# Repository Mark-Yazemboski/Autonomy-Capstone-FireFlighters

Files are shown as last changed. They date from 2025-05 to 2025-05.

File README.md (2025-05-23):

# 🔥 Autonomous Fire Fighting Drone

## A functional, affordable, and easily buildable drone capable of searching an area, detecting a heat source, and deploying a payload.  
🏆 **First Place Winner – Senior Capstone Showcase**

This senior capstone project’s objective was to design and build a drone capable of autonomously searching a designated area, locating a simulated fire using a thermal camera, and deploying a fire suppressant. Teams were given only the following components: an **Arduino**, a **thermal camera**, a **transmitter/receiver**, and an **IMU**.

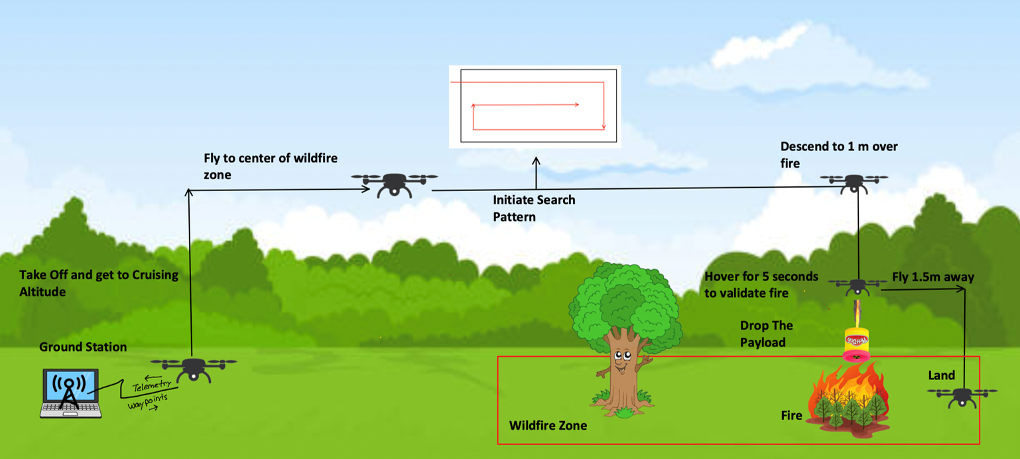
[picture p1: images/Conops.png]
Mission Concept


> 👨‍🚒 **Team Name:** *The FireFlighters*

---

## 📸 Team Photo

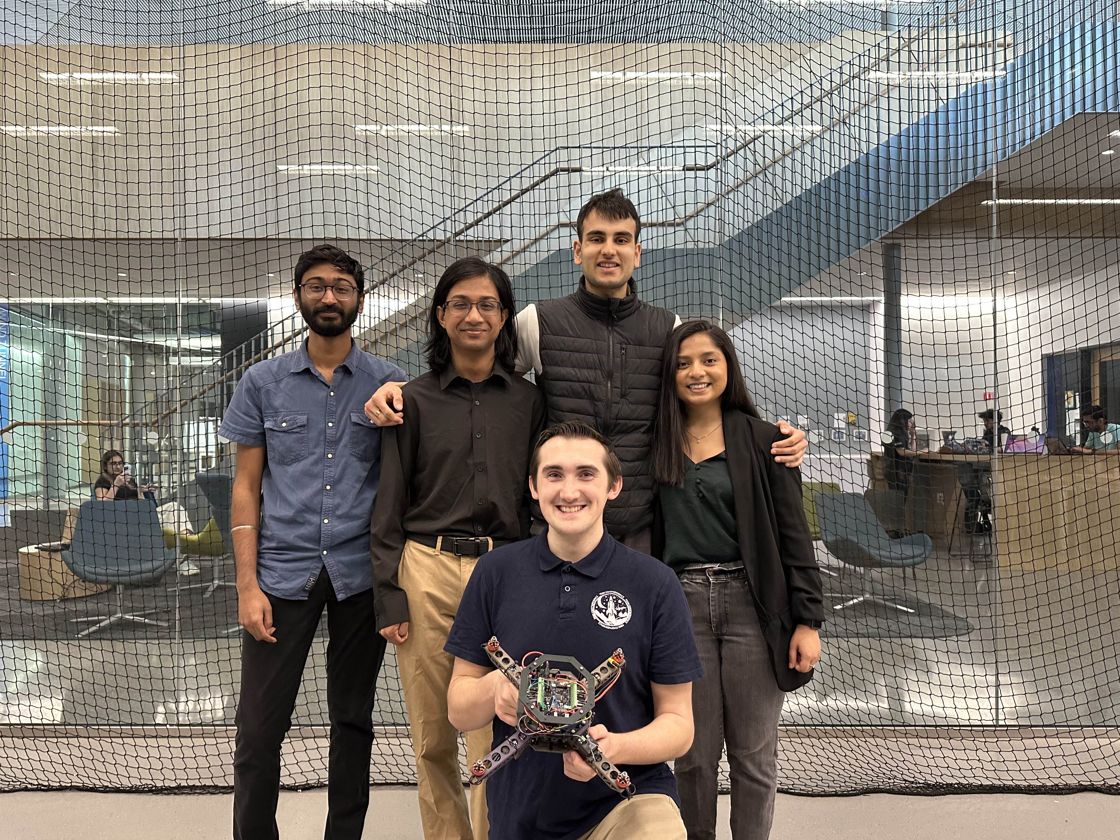
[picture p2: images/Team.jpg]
Team Photo


**Team Members (left to right):**

- **Achutan Srinivasan** – Back Left  
- **Ankur Ghorai** – Back Middle Left  
- **Jaisel Singh** – Back Middle Right  
- **Trusha Patel** – Back Right  
- **Mark Yazemboski** (👋 Me, Front) – *Team Lead*

---

## 🛠️ Key Design Principles

We focused on four core physical design goals:

- ✅ Fully 3D-printed frame  
- 🛒 Easily obtainable parts (Amazon, GetFPV, etc.)  
- 🧩 Modular, repairable design  
- ⚡ Clean and efficient wire management  

---

## 💡 Design Rationale

After studying past teams, we identified key ways to improve:

- **3D-printed frame** for rapid repair and low cost  
- **Fast-shipping parts** to avoid long lead times  
- **Modular design** allowed broken parts (like arms) to be replaced in hours  
- **Wire routing** designed into the frame to prevent tangles and shorts  

---

## 🧠 Drone Architecture (CAD Model)

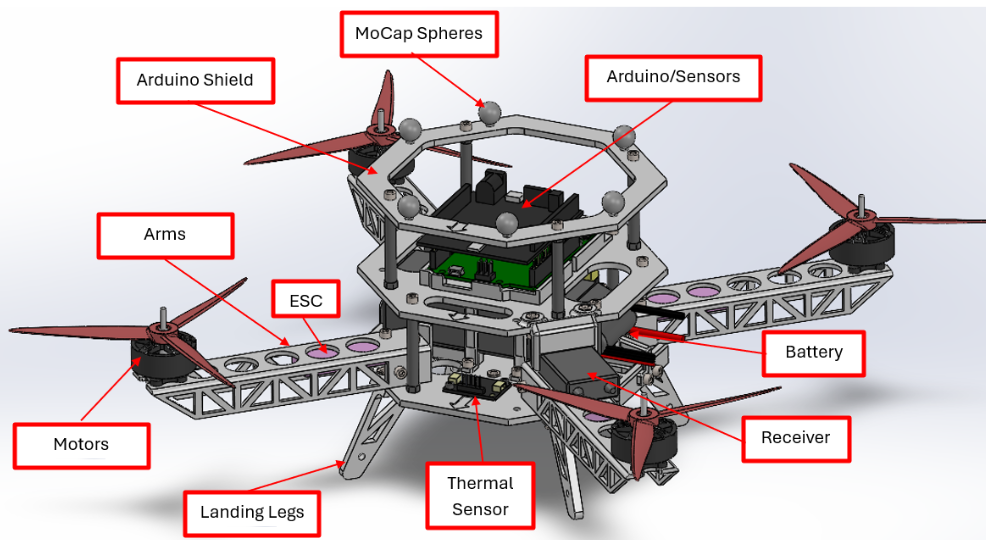
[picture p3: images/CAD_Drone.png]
CAD Model


A three-tier frame layout:

1. **Base Plate**  
   - Mounts arms, battery, PDB, payload, and ESCs  
   - Central structure for mechanical and electrical subsystems  

2. **Top Plate**  
   - Mounts the Arduino and IMU  
   - Raised to reduce EMI from high-current motor lines  

3. **Shield**  
   - Holds MoCap markers for position tracking  
   - Protects sensitive electronics during crashes  

---

## ✈️ Arm Design

The custom arm design used a **C-beam profile with trusses**:

- **C-channel** let us route ESCs and wires inside the arm  
- **Trusses** reduced weight while maintaining strength  
- These features improved stiffness and flight stability despite the printed frame  

---

## 🖨️ 3D Printing & Cost Efficiency

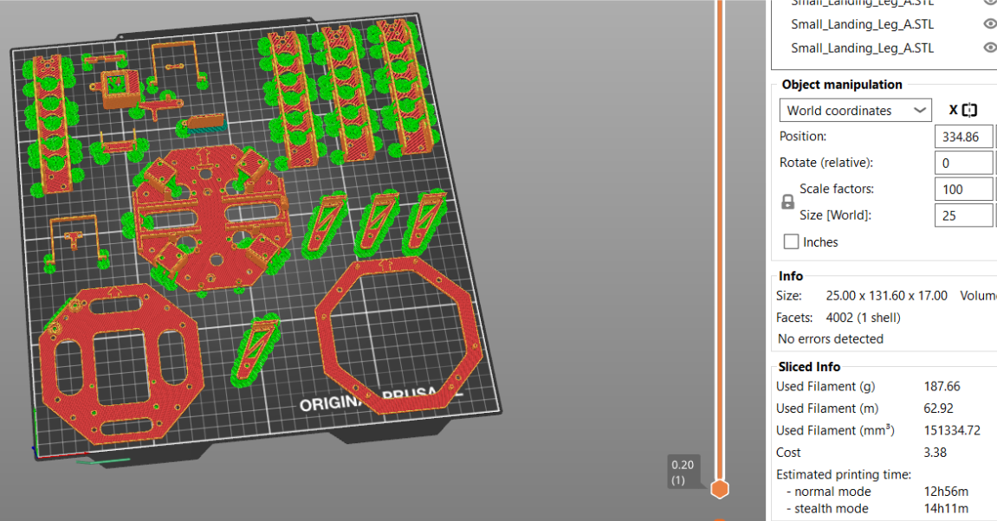
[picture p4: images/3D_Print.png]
3D Print Layout


- Printed using **PLA on a Prusa XL**  
- **Total print time:** ~13 hours  
- **Material cost:** ~$3.38  
- Demonstrated that UAVs can be affordable and manufacturable quickly  

---

## 📂 Repository Contents

- **Drone CAD/** – All SolidWorks models with accurate weight/inertia  
- **STL_and_Prusa_Files/** – Printable files for all drone parts + pre-arranged Prusa slicer project  
- **Build_Book.pdf** – Step-by-step construction and setup guide  
- **FireFlighters_Drone_BOM.xlsx** – Full bill of materials with costs and part links  
- **ManualFlightCode/** – Arduino code for manual RC flight  
- **HandCarryCode/** – Contains full autonomy logic (not flight-ready)  
- **Matlab_Kalman_Filter_Prototype.m** – MATLAB simulation of the onboard Kalman Filter  
- **Thermal_Sensor_Simulation.py** – Python simulation of the thermal camera behavior  
- **Final_Report.pdf** – Technical report covering the full design, testing, and conclusions  

---

## 🧪 Issues Encountered

The **Arduino Uno**, while functional, lacks the processing power and **multithreading capabilities** needed for real-time autonomous flight. Specifically:

- The **GCS communication protocol** took ~100 ms per loop iteration  
- This limited the control loop to ~2 Hz (instead of the desired 100+ Hz)  
- The drone couldn't stabilize itself while processing communication, sensor input, and control logic all on the same thread  

As a workaround, the drone was hand-carried during the demo to showcase data transmission, Kalman filter-based orientation and position estimation, waypoint tracking, search pattern execution, thermal detection, and payload deployment.

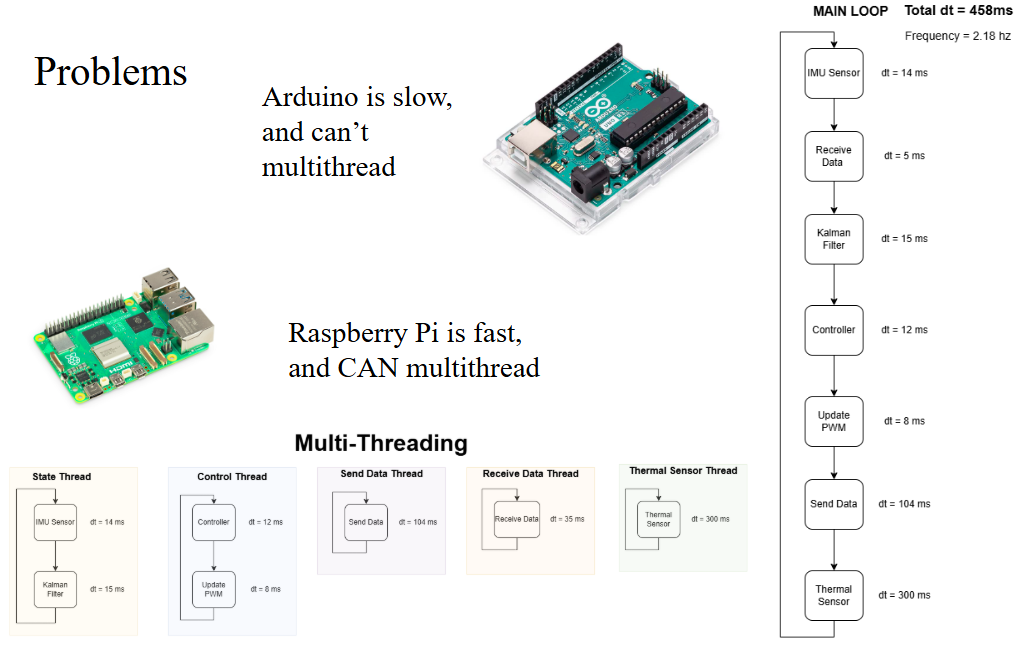
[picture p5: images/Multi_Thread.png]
Multithreading Bottleneck


### 🔧 Future Recommendation

Next year's team will upgrade to a **Raspberry Pi**, which supports:

- Multithreading (e.g., separate threads for GCS comms and control loop)  
- Faster processing for real-time autonomy  
- More flexible development in Python or C++  

---

## 🧾 Conclusion

This capstone project was an incredible learning experience. Building a product from the ground up taught me far more than I expected—not just about **CAD** and designing components for manufacturability and ease of assembly, but also about algorithms and core topics in **autonomy**.

I deepened my understanding of **Kalman filters** (my personal favorite), learned how to implement **cascade PID controllers**, developed **waypoint navigation**, and wrote the full autonomy codebase. This project challenged and refined my programming skills and solidified my passion for **Guidance, Navigation, and Control (GNC)** and **autonomous systems**.

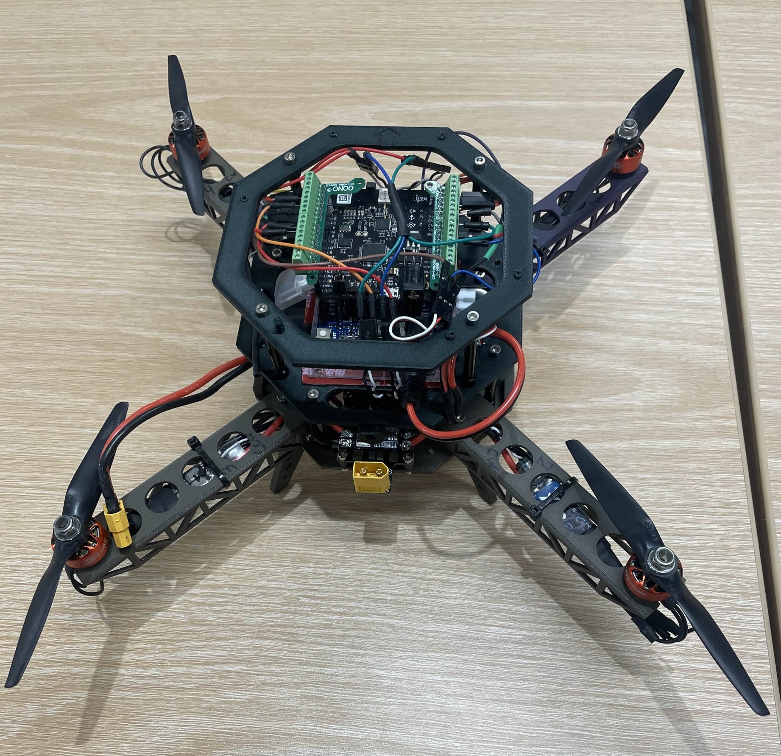
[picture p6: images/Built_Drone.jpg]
Final Drone


Thank you!

## 📄 Final Report

For complete technical details on design, components, control logic, testing, and results, see the [**Final Report**](Final_Report.pdf).

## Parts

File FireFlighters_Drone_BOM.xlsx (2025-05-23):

FireFlighters Drone BOM
Part Description | Model (if available) | Website (just name) | Units | Cost per Unit | Total | Comments | Links
Prop | B5x3E-B4 | APC Props | 1 | $5.63 | $5.63 |  | Link (https://www.apcprop.com/product/b5x3e-b4/)
Motor | RCINPOWER SmooX 1507 | Get FPV | 4 | $18.99 | $75.96 | Orange Color, 2680KV | Link (https://www.getfpv.com/rcinpower-smoox-1507-plus-2680kv-3800kv-4200kv-motor.html)
ESC | XILO 40A BLHeli_S 2-4s ESC | Get FPV | 4 | $12.99 | $51.96 |  | Link (https://www.getfpv.com/xilo-40a-blheli-s-2-4s-esc.html)
Battery | OVONIC 4s Lipo 2200 mAh | Amazon | 1 | $25.99 | $25.99 |  | Link (https://www.amazon.com/2200mAh-Airplane-Quadcopter-Helicopter-Multi-Motor/dp/B07MLF5G1T)
Spacers | Aluminum Standoff Spacer | Amazon | 2 | $11.99 | $23.98 |  | Link (https://www.amazon.com/dp/B0B97H2WJ7?ref=ppx_yo2ov_dt_b_fed_asin_title)
M2 screw | M2 Screws Kit M2 Bolts Kit | Amazon | 1 | $8.99 | $8.99 |  | Link (https://www.amazon.com/dp/B0D3X4LJD2?ref=ppx_yo2ov_dt_b_fed_asin_title)
M3 Screw | M3 Small Metric Screws | Amazon | 1 | $15.99 | $15.99 |  | Link (https://www.amazon.com/dp/B0CMQG542V?ref=ppx_yo2ov_dt_b_fed_asin_title)
PDB | Matek Systems PDB-XT60 W/ BEC 5V & 12V 2oz Copper For RC Multirotors | Foxtech FPV | 1 | $4.49 | $4.49 |  | Link (https://www.foxtechfpv.com/matek-pdb-xt60-for-rc-multirotors.html)
Arduino Terminal Block | Ultra-Small GPIO Terminal Block Breakout Board Module for Arduino UNO R3 | Amazon | 1 | $18.90 | $18.90 |  | Link (https://www.amazon.com/dp/B08XWCN43C?ref=ppx_yo2ov_dt_b_fed_asin_title)
Servo | Turnigy TGY-1551A Analog Micro Servo 24T 1.0kg / 0.08sec / 5g | Hobby King | 1 | $2.39 | $2.39 |  | Link (https://hobbyking.com/en_us/turnigy-tgy-1551a-analog-micro-servo-1-0kg-0-08sec-5g.html)
Arduino | Arduino Uno R4 Wifi | Arduino | 1 | $27.50 | $27.50 |  | Link (https://store-usa.arduino.cc/products/uno-r4-wifi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)
Pozyx | Pozyx Shield V1.6 | Pozyx | 1 | $20.00 | $20.00 | Out of Stock | Link (https://www.pozyx.io/products/hardware/tags/developer-tag)
Reciever/Transmitter | FS-i6X 10CH 2.4GHz RC Transmitter Controller with FS-iA6B Receiver | Amazon | 1 | $58.84 | $58.84 |  | Link (https://www.amazon.com/FLYSKY-Transmitter-Controller-Receiver-Upgrade/dp/B07Z8VCB45)
Arduino Power Cord | 5 Pcs 5.5x2.1mm Male for Power Plug Connector CCTV Pigtail Cable 12V | Amazon | 1 | $5.71 | $5.71 | Comes with 5 | Link (https://www.amazon.com/Hxyxbnhno-5-5x2-1mm-Power-Connector-Pigtail/dp/B0DGSSD4BF)
Zipties | Cable Zip Ties,400 Pack Black Assorted Sizes 12+8+6+4 Inch,Multi-Purpose Self-Locking | Amazon | 1 | $5.99 | $5.99 |  | Link (https://www.amazon.com/HAVE-ME-TD-Cable-Ties/dp/B08TVLYB3Q?s=electronics)
Electrical Tape | 0.62 in x 49 ft, 3 Pack, Electric Tape | Amazon | 1 | $4.85 | $4.85 |  | Link (https://www.amazon.com/Bates-Black-Electrical-8A9Wt3hrxTG8qXQFjeyNLkF9a9AJPfWWxSc6Fyv4suBe2xqZMGFbhrnMSRysAEYuT7LzpBsTYM4RJ8V2xWghttbNRG4Luiu-Eletrical/dp/B0B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)
Type C to USB | able 3ft, 2-Pack USB A to Type C Charger Cord Fast Charging | Amazon | 1 | $5.99 | $5.99 |  | Link (https://www.amazon.com/Charging-etguuds-Charger-Compatible-Samsung/dp/B089DM4KDW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)
PLA | PLA Filament | Amazon | 1 | $14.99 | $14.99 | Any Color | Link (https://www.amazon.com/OVERTURE-Filament-Consumables-Dimensional-Accuracy/dp/B07PGZNM34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)
Wire | 22 awg Wire Solid Core Hookup | Amazon | 1 | $15.19 | $15.19 | 22 AWG 6 Colors Solid Wire Kit | Link (https://www.amazon.com/TUOFENG-Electronic-Prototyping-Circuits-Breadboarding/dp/B07TX6BX47?s=industrial)
Thermal Camera | Adafruit MLX90640 IR Thermal Camera Breakout - 55 Degree | Adafruit | 1 | $74.95 | $74.95 | Optional for manual flight | Link (https://www.adafruit.com/product/4407)
Color Code |  | Total Cost
Nessesary Items |  | $346.33
Items you might already own |  | $47.01
Optional/ Wont effect manual flight |  | $74.95
Full Cost for Everything
$468.29

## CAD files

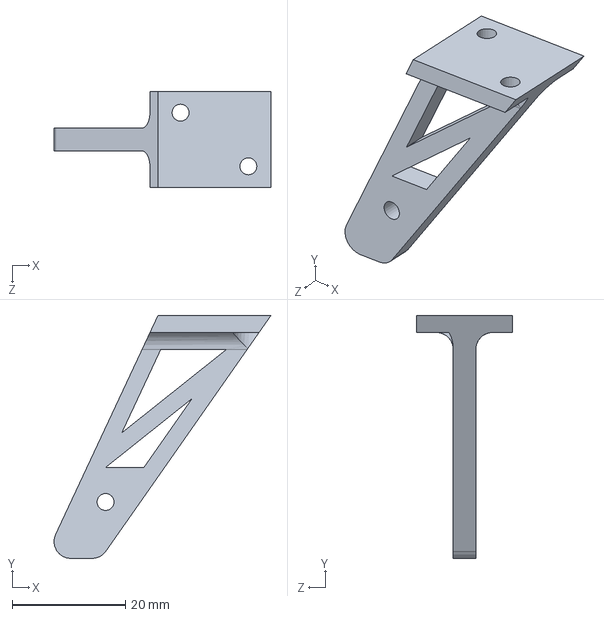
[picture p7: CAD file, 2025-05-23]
Drone CAD/Frame-Structural-Models/Small_Landing_Leg_A.SLDPRT
38.4 x 43.0 x 17.0 mm

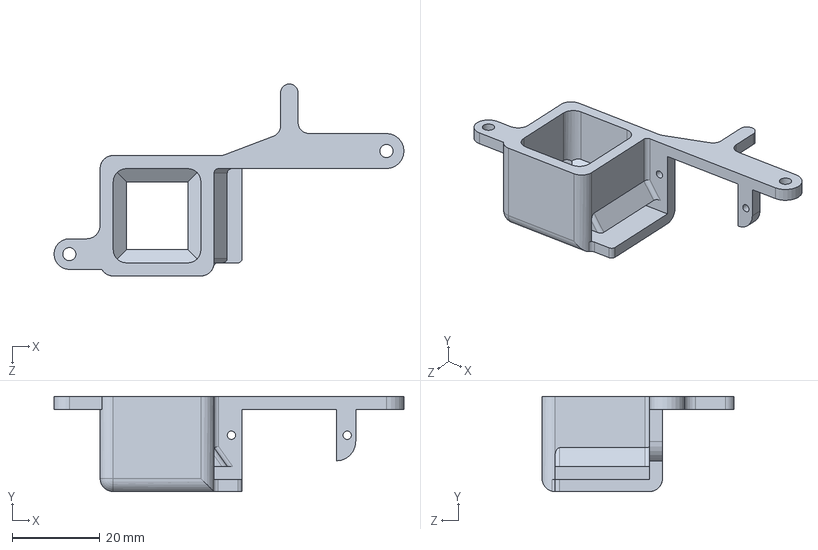
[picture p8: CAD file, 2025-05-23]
Drone CAD/New_Sliding_Door_Payload_Mechanism/Payload_Mount_E.SLDPRT
79.8 x 21.7 x 43.8 mm

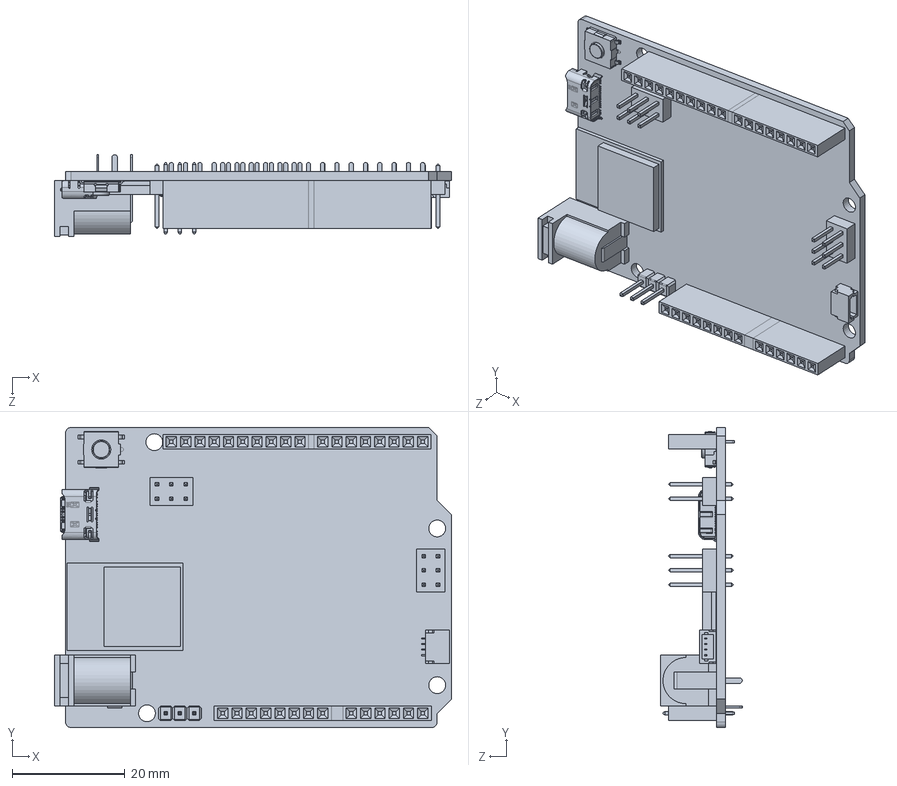
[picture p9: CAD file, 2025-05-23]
Drone CAD/Sensors-Electronics/Arduino_Uno_R4_Wifi_A.SLDPRT
70.5 x 53.3 x 14.5 mm

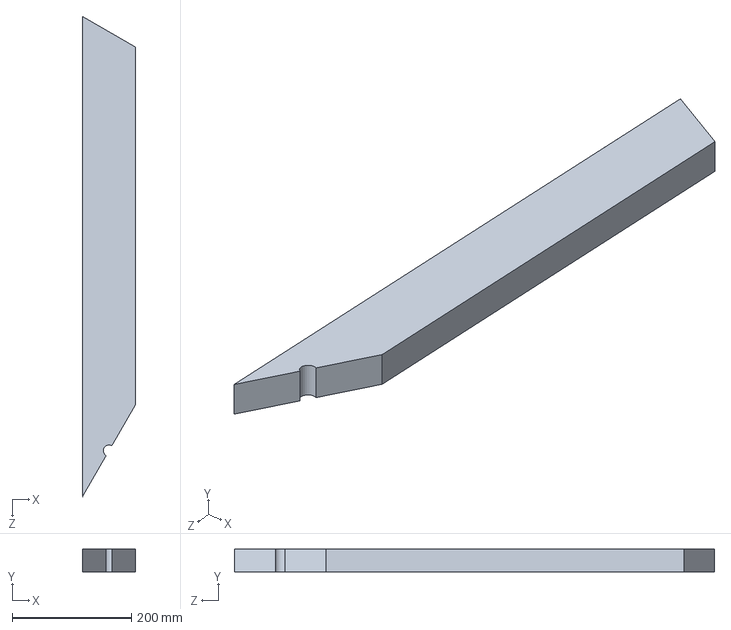
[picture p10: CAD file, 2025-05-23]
Drone CAD/Test_Stand/Long_2by4.SLDPRT
88.9 x 38.1 x 806.6 mm

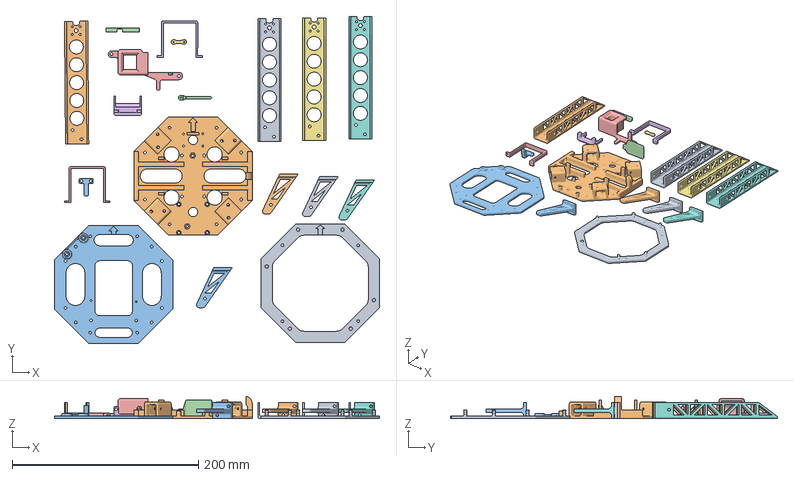
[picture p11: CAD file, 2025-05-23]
STL_and_Prusa_Files/Entire_Drone_Prusa_XL.3mf
348.6 x 351.2 x 23.8 mm
6inch_Arm_D.STL x 4
Battery_Holder_D.STL
Flat_Head_Pin_E.STL
Payload_Mount_E.STL
Reciever_Holder_B.STL
Servo_To_Flat_Head_Pin_C.STL
Small_Landing_Leg_A.STL x 4
Shield_Plate_C.STL
Base_Plate_G.STL
Top_Plate_E.STL
PDB_Wire_Holder_A.STL
Battery_Bracket_B.STL x 2

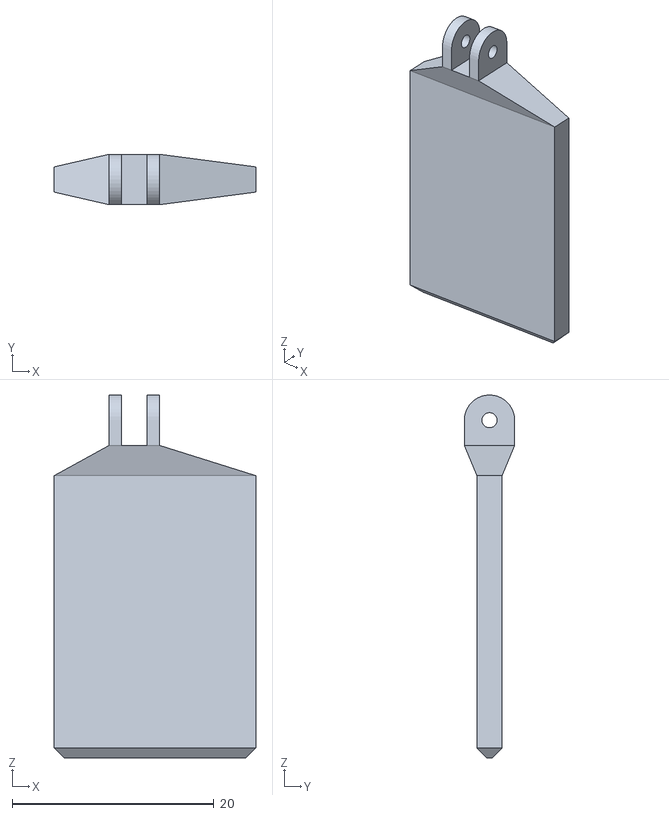
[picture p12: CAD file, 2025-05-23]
STL_and_Prusa_Files/STLs/Flat_Head_Pin_E.STL
20.0 x 5.00 x 36.0

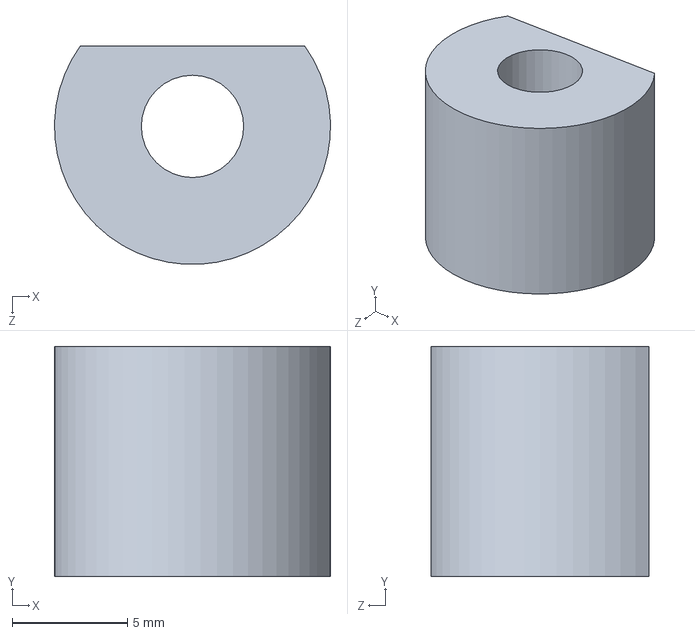
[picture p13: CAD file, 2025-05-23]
Drone CAD/Frame-Structural-Models/Wire_Cylinder.SLDPRT
12.0 x 10.0 x 9.49 mm

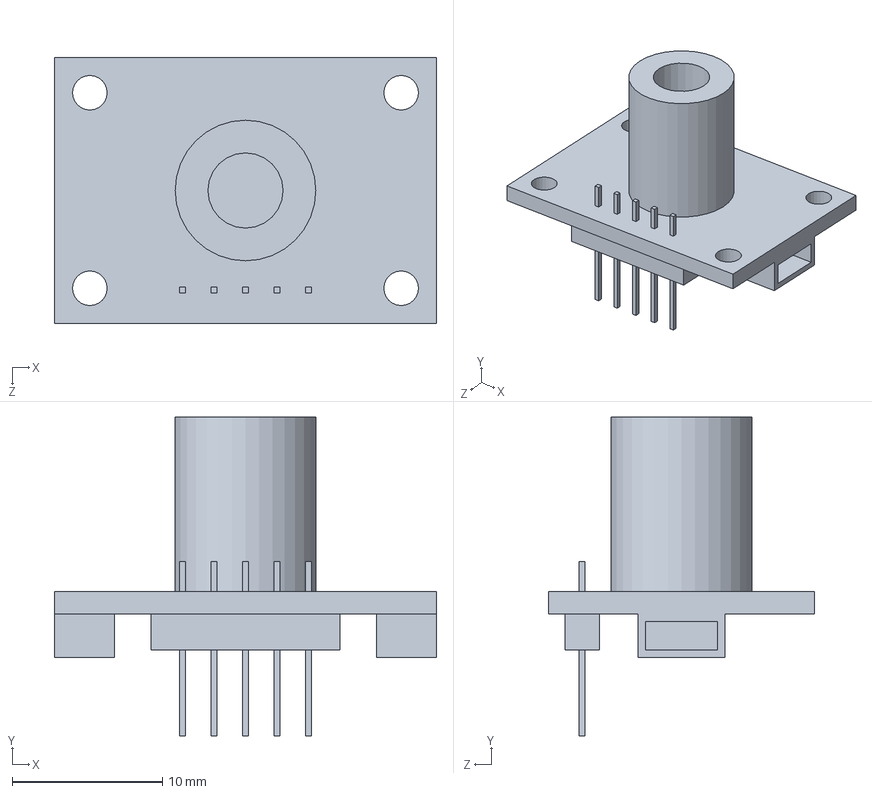
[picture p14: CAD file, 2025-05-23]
Drone CAD/Sensors-Electronics/IR_Sensor_B.SLDPRT
25.4 x 21.2 x 17.7 mm

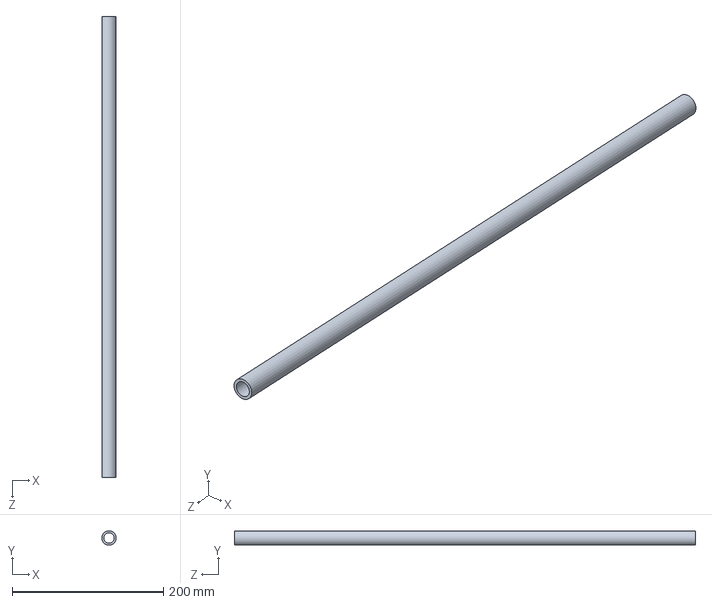
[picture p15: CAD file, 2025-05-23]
Drone CAD/Test_Stand/Rod.SLDPRT
19.1 x 19.0 x 609.6 mm

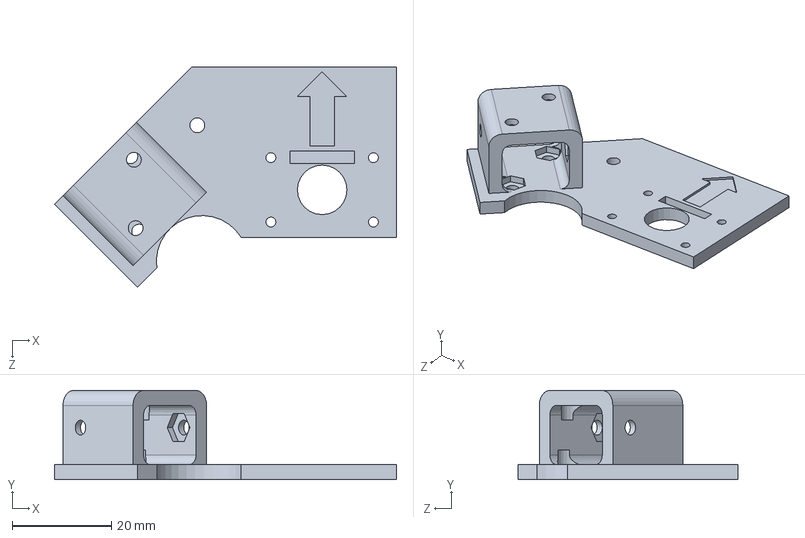
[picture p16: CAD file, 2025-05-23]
Drone CAD/Tests/Thermal_Arm_Test.SLDPRT
69.0 x 18.0 x 44.5 mm

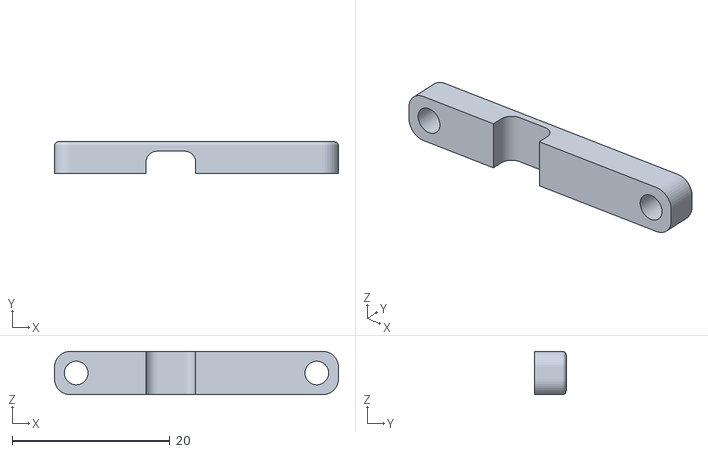
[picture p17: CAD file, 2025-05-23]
STL_and_Prusa_Files/STLs/PDB_Wire_Holder_A.STL
36.0 x 4.00 x 5.50

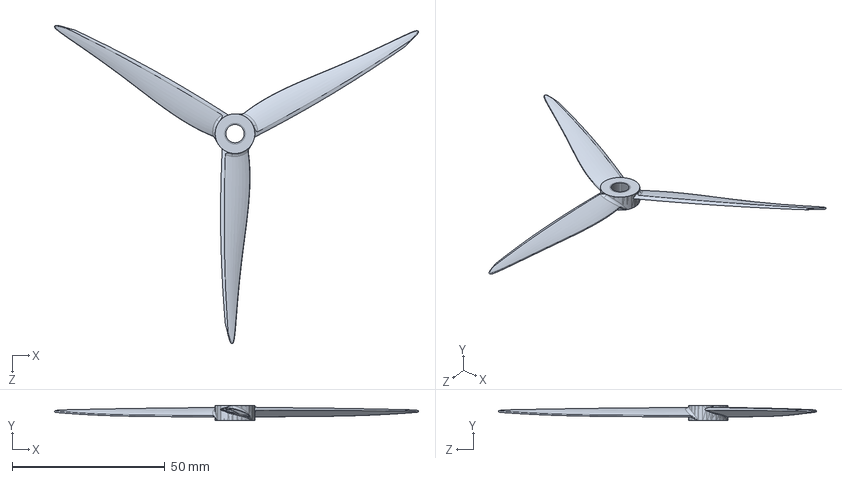
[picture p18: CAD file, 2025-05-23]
Drone CAD/Frame-Structural-Models/6_inch_Propeller_A.SLDPRT
119.1 x 5.00 x 104.2 mm

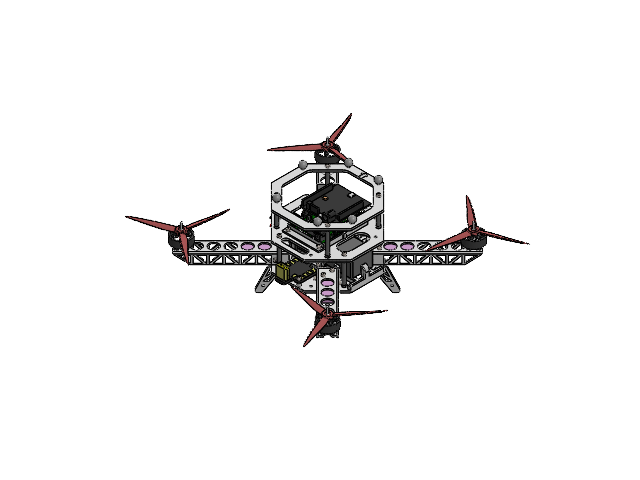
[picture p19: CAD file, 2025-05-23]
Drone CAD/Full_Drone_Assembly.SLDASM
Base_Plate_G
Servo_Arm_A
Payload_Mount_E
Servo_To_Flat_Head_Pin_C
Flat_Head_Pin_E
Servo_A
IR_Sensor_B
Motor_B x 4
ESC_A x 4
Battery_Holder_D
Stand_Off_40_B x 8
Top_Plate_E
Arduino_Mount_B
Arduino_Uno_R4_Wifi_A
Pozyx-shield_A
6_inch_Propeller_A x 4
Shield_Plate_C
6inch_Arm_D x 4
Reciever_A
Reciever_Holder_B
Power_Distribution_Board_C
Small_Landing_Leg_A x 4
M3_6 x 20
M3_8 x 14
M3_Nut x 59
M3_10 x 21
Battery_D
Battery_Bracket_B x 2
PDB_Wire_Holder_A
XT60
Ball x 6
M2_Nut x 4
M3_14 x 2
M3_16 x 2
M2_12 x 2
M2_6 x 2

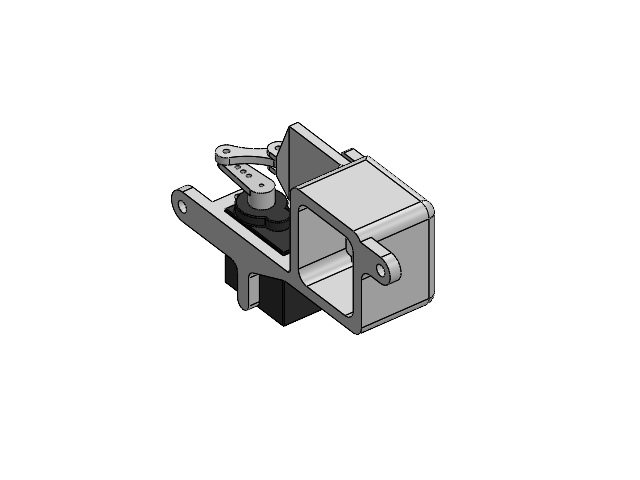
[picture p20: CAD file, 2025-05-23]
Drone CAD/New_Sliding_Door_Payload_Mechanism/Payload_Mechanism_Sliding_Door_F.SLDASM
Servo_Arm_A
Payload_Mount_E
Servo_To_Flat_Head_Pin_C
Flat_Head_Pin_E
Servo_A

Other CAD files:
Drone CAD/Test_Stand/Test_Stand.SLDASM
Drone CAD/Sensors-Electronics/Arduino_And_GPS_Module_C.SLDASM
Drone CAD/Sensors-Electronics/Arduino_With_Mount_B.SLDASM
Drone CAD/New_Sliding_Door_Payload_Mechanism/Flat_Head_Pin_E.SLDPRT
Drone CAD/Fasteners/Bar_Clamp.SLDASM
Drone CAD/Fasteners/M2_12.SLDPRT
Drone CAD/Fasteners/M2_20.SLDPRT
Drone CAD/Fasteners/M2_4.SLDPRT
Drone CAD/Fasteners/M2_6.SLDPRT
Drone CAD/Fasteners/M2_Nut.SLDPRT
Drone CAD/Fasteners/M3_10.SLDPRT
Drone CAD/Fasteners/M3_14.SLDPRT
Drone CAD/Fasteners/M3_16.SLDPRT
Drone CAD/Fasteners/M3_6.SLDPRT
Drone CAD/Fasteners/M3_8.SLDPRT
Drone CAD/Fasteners/M3_Nut.SLDPRT
Drone CAD/Fasteners/Test_Stand_Stopper_Nut_Part.SLDPRT
Drone CAD/Fasteners/Test_Stand_Stopper_Screw_Part.SLDPRT
Drone CAD/Frame-Structural-Models/6inch_Arm_D.SLDPRT
Drone CAD/Frame-Structural-Models/Ball.SLDPRT
Drone CAD/Frame-Structural-Models/Base_Plate_G.SLDPRT
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

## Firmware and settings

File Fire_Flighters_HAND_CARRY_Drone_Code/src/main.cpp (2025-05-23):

/*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
 * Pennsylvania State University Unmanned Aerial System Research Laboratory (PURL)
 * Department of Aerospace Engineering
 * 229 Hammond
 * The Pennsylvania State University
 * University Park, PA 16802
 * http://purl.psu.edu
 *
 * Contact Information:
 * Dr. Thanakorn Khamvilai (thanakorn.khamvilai@ttu.edu)
 * Dr. Vitor T. Valente (vitor.valente@psu.edu)
 *
 * EndCopyright
 ***/

#include "../include/main.h"
#include "../include/Pozyx_definitions.h"
//#include "avr8-stub.h"


 #define HAVE_DATALINK    1
 #define HAVE_MOCAP       true
 #define HAVE_IMU         1
 #define HAVE_RC_RECEIVER 0
 #define HAVE_MOTORS      0
 #define HAVE_THERMAL     1
 #define HAVE_CONTROLLER  1
 #define HAVE_KALMAN      1
 #define PRINT_DT         0
 #define PRINT_KILL_AUTO_PAYLOAD 0

#define MIN_PWM 1000 //I ADDED THIS
#define MAX_PWM 1980//I ADDED THIS
#define LIMIT(x,xl,xu) ((x)>=(xu)?(xu):((x)<(xl)?(xl):(x)))//I ADDED THIS

/* Values in ms -> for Freq = 1000/value */
const unsigned long intervalIMU = 10;
const unsigned long intervalRC = 10;
const unsigned long intervalMotors = 10;
const unsigned long intervalDatalink_Recieve = 10;
const unsigned long intervalThermal = 1200;
const unsigned long intervalPrint = 100;
const unsigned long intervalCtrl = 10;
const unsigned long intervalNav = 10;
const unsigned long intervalData_Link_Send = 10;

unsigned long previousMillisIMU = 0;
unsigned long previousMillisRC = 0;
unsigned long previousMillisMotors = 0;
unsigned long previousMillisDatalink_Recieve = 0;
unsigned long previousMillisThermal = 0;
unsigned long previousMillisCntrl = 0;
unsigned long previousMillisPrint = 0;
unsigned long previousMillisNav = 0;
unsigned long previousData_Link_Send = 0;
bool Fire_Found = false;
float Fire_Position[3] = { 0,0,0 };
float Opened_Time = 0;
bool Opened = false;
float Open_Time = 0;

// float Gyro_Corrected_wx;
// float Gyro_Corrected_wy;
// float Gyro_Corrected_wz;

// float Gyro_Corrected_euler_phi;
// float Gyro_Corrected_euler_theta;
// float Gyro_Corrected_euler_psi;


void update_Previous_Time_Values()
{
  previousMillisIMU = millis();
  previousMillisRC = millis();
  previousMillisMotors = millis();
  previousMillisDatalink_Recieve = millis();
  previousMillisThermal = millis();
  previousMillisCntrl = millis();
  previousMillisPrint = millis();
  previousMillisNav = millis();
  previousData_Link_Send = millis();
}




void updateMixer( const char button0, char* LaunchState,
  float c_delf, float c_delm0, float c_delm1, float c_delm2,
  float* PWM)//I ADDED THIS
{
  // mixer
  if ( 1 == button0 ) // arm
  {
  *LaunchState = 1;

  // only throttle and roll
  float thr_pwm = ( c_delf - ( -1 ) ) * ( 2000 - 1000 ) / ( 1 - ( -1 ) ) + 1000; // from [-1,1] to [1000,2000]
  float roll_pwm = ( c_delm0 - ( -1 ) ) * ( 500 - ( -500 ) ) / ( 1 - ( -1 ) ) + ( -500 ); // from [-1,1] to [-500,500]
  float pitch_pwm = ( c_delm1 - ( -1 ) ) * ( 500 - ( -500 ) ) / ( 1 - ( -1 ) ) + ( -500 ); // from [-1,1] to [-500,500]
  float yaw_pwm = ( c_delm2 - ( -1 ) ) * ( 500 - ( -500 ) ) / ( 1 - ( -1 ) ) + ( -500 ); // from [-1,1] to [-500,500]

  PWM[0] = ( float ) LIMIT( thr_pwm - roll_pwm - pitch_pwm - yaw_pwm, MIN_PWM, MAX_PWM ); // front-right CCW
  PWM[1] = ( float ) LIMIT( thr_pwm - roll_pwm + pitch_pwm + yaw_pwm, MIN_PWM, MAX_PWM ); // back-right  CW
  PWM[2] = ( float ) LIMIT( thr_pwm + roll_pwm + pitch_pwm - yaw_pwm, MIN_PWM, MAX_PWM ); // back-left   CCW
  PWM[3] = ( float ) LIMIT( thr_pwm + roll_pwm - pitch_pwm + yaw_pwm, MIN_PWM, MAX_PWM ); // front-left  CW
  }
  else // disarm
  {

  #if PRINT_KILL_AUTO_PAYLOAD  
    Serial.println("KILLED");
  #endif
  *LaunchState = 0;
  PWM[0] = MIN_PWM;
  PWM[1] = MIN_PWM;
  PWM[2] = MIN_PWM;
  PWM[3] = MIN_PWM;
  }
}

float mapStickInput(float input) {
  return (((input - 900) * 2.0 / (2000 - 900)) - 1.0);
}

void setup(){
    //Initialize serial and wait for port to open:
    Serial.begin(9600);
    //debug_init();
    while (!Serial) {
      ;
    }
    

    
    
    #if HAVE_THERMAL
    Serial.println("Initilizing thermal");
    // initialize thermal camera
    thermal.init();
    Serial.println("Finished Initilizing thermal");
    #endif
    
    
    
    #if HAVE_DATALINK
    Serial.println("Initilizing datalink");
    // initialize wifi
    datalink.init();
    Serial.println("Finished Initilizing datalink");
    #endif
    

    
    #if HAVE_IMU
    Serial.println("Initilizing sens");
    // initialize sensors
    sens.init();
    Serial.println("Finished Initilizing sens");
    #endif
    
    
    
    #if HAVE_RC_RECEIVER
    Serial.println("Initilizing rc");
    // initialize rc
    rc.init();
    Serial.println("Finished Initilizing rc");
    #endif
    


    

    
    
    


    Serial.println("Initilizing motors");
    // initialize motors/servos
    for (int i=0; i<NUM_MOTORS; i++){
        pwm[i] = MIN_PWM_OUT;
    }
    
    motors.init();
    //motors.calibrate();
    Serial.println("Finished Initilizing motors");
   
    update_Previous_Time_Values();
    Serial.println("Starting Drone!");
 }

void loop(){
    struct onboardControl_ref* cntrl = &onboardControl;
    struct My_Kalman_ref* EKF = &MyEKF;
    struct My_navout_ref* My_Out = EKF->out;
    
  
    float c_delf = 0, c_delm[3] = { 0,0,0 };
    /* The order should be:
        1-) Read all sensors and data
        2-) Perform calculations
        3-) Motor actuation
        4-) Update data on GCS
    */
    unsigned long currentMillis = millis();


    #if HAVE_IMU
    currentMillis = millis();
    sens.update();
    #if PRINT_DT
    Serial.println("Sensors");
    Serial.println(millis()- currentMillis);
    #endif
    #endif
    
    #if HAVE_RC_RECEIVER
    currentMillis = millis();
    if (currentMillis - previousMillisRC >= intervalRC) {
      previousMillisRC = currentMillis;
        rc.update();
    }
    #if PRINT_DT
    Serial.println("RC");
    Serial.println(millis()- currentMillis);
    #endif
    #endif

    


    #if HAVE_DATALINK
    currentMillis = millis();
    if (currentMillis - previousMillisDatalink_Recieve >= intervalDatalink_Recieve) {
      previousMillisDatalink_Recieve = currentMillis;
      datalink.recv_update(&sens, HAVE_MOCAP);
    }

    // Serial.print(sens.data_MoCap.Euler_Angles[0]);
    // Serial.print(" , ");
    // Serial.print(sens.data_POZYX.euler[0]);
    // Serial.println();
    // Serial.println("Begin");
    // Serial.print(sens.data_MoCap.Pos[0]);
    // Serial.print("\t ");
    // Serial.print(sens.data_MoCap.Pos[1]);
    // Serial.print("\t ");
    // Serial.print(sens.data_MoCap.Pos[2]);
    // Serial.print("\t ");
    // Serial.print(sens.data_MoCap.Quat[0]);
    // Serial.print("\t ");
    // Serial.print(sens.data_MoCap.Quat[1]);
    // Serial.print("\t ");
    // Serial.print(sens.data_MoCap.Quat[2]);
    // Serial.print("\t ");
    // Serial.println(sens.data_MoCap.Quat[3]);
    // Serial.println("End");
    #if PRINT_DT
    Serial.println("Datalink");
    Serial.println(millis()- currentMillis);
    #endif
    #endif

    #if HAVE_KALMAN
    currentMillis = millis();
    /* Navigation stuff goes here */
    if (currentMillis - previousMillisNav >= intervalNav) {
      double dt = (currentMillis - previousMillisNav)/1000.0;
      previousMillisNav = currentMillis;
      updateNavigation(dt,sens,Fire_Found,(float)My_Out->Fire_Location[0],(float)My_Out->Fire_Location[1],My_Out->Payload_Dropped);
      //Serial.println(dt);
    }
    #if PRINT_DT
    Serial.println("Navigation");
    Serial.println(millis()- currentMillis);
    #endif
    #endif

    

    /* Controller stuff goes here */
    
    #if HAVE_CONTROLLER
    currentMillis = millis();
    if (currentMillis - previousMillisCntrl >= intervalCtrl) {
      //I ADDED ALL OF THIS
      float dt = (currentMillis - previousMillisCntrl)/1000;
      previousMillisCntrl = currentMillis;

      //This will recieve the 900-2000 pwm signals from the reciever
      float Throttle_Stick = rc.rc_in.THR;
      float Roll_Stick = rc.rc_in.ROLL;
      float Pitch_Stick = rc.rc_in.PITCH;
      float Yaw_Stick = rc.rc_in.YAW;
      float KILL_SWITCH_Value = rc.rc_in.AUX;
      float Auto_Manual_Payload_SWITCH_Value = rc.rc_in.AUX2;

      //This will map those values between -1 and 1
      float Throttle_Stick_Mapped = mapStickInput(Throttle_Stick);
      float Roll_Stick_Mapped     = mapStickInput(Roll_Stick);
      float Pitch_Stick_Mapped    = mapStickInput(Pitch_Stick);
      float Yaw_Stick_Mapped      = mapStickInput(Yaw_Stick);



      
      
      bool Arm_Switch_State; //Arm is True; kill is false
      //Added detection to see if the reciever lost power, or the kill wire came loose. This will auto kill the drone.
      if (rc.rc_in.Good_Reciever && rc.rc_in.Good_Kill_Wire){
        if (KILL_SWITCH_Value > 1500){
          Arm_Switch_State = false;
        }else{
          Arm_Switch_State = true;
        }
      }else{
        Arm_Switch_State = false;
      }

      int Auto_Manual_Payload_State;//2 is manual Payload drop; 1 is manual; 0 is auto
      bool Manual;
      if (Auto_Manual_Payload_SWITCH_Value > 1700){
        Auto_Manual_Payload_State = 2;
        Manual = true;
      }else if (Auto_Manual_Payload_SWITCH_Value > 1200){
        Auto_Manual_Payload_State = 1;
        Manual = true;
      }else{
        Auto_Manual_Payload_State = 0;
        Manual = false;
      }
      
      if (Auto_Manual_Payload_State == 1 || Auto_Manual_Payload_State == 2){
          
        //   updateControl(dt, (float)cntrl->phiCmd,
				// (float)cntrl->posDes[0], (float)cntrl->posDes[1], (float)cntrl->posDes[2],
				// (float)My_Out->p_b_e_L[0], (float)My_Out->p_b_e_L[1], (float)My_Out->p_b_e_L[2],
				// (float)My_Out->v_b_e_L[0], (float)My_Out->v_b_e_L[1], (float)My_Out->v_b_e_L[2],
				// (float)My_Out->w_b_e_B[0], (float)My_Out->w_b_e_B[1], (float)My_Out->w_b_e_B[2],
				// (float)My_Out->phi, (float)My_Out->theta, (float)My_Out->psi,
				// (float)My_Out->a_b_e_L[0], (float)My_Out->a_b_e_L[1], (float)My_Out->a_b_e_L[2],
				// &c_delf, &c_delm[0], &c_delm[1], &c_delm[2],
        // Throttle_Stick_Mapped,Roll_Stick_Mapped,Pitch_Stick_Mapped,Yaw_Stick_Mapped,Manual,!Arm_Switch_State);

        updateControl(dt, (float)cntrl->phiCmd,
				(float)cntrl->posDes[0], (float)cntrl->posDes[1], (float)cntrl->posDes[2],
				(float)My_Out->p_b_e_L[0], (float)My_Out->p_b_e_L[1], (float)My_Out->p_b_e_L[2],
				(float)My_Out->v_b_e_L[0], (float)My_Out->v_b_e_L[1], (float)My_Out->v_b_e_L[2],
				sens.data_POZYX.gyr_rad[0],sens.data_POZYX.gyr_rad[1],sens.data_POZYX.gyr_rad[2],
				sens.data_POZYX.euler_rad[0], sens.data_POZYX.euler_rad[1],sens.data_POZYX.euler_rad[2],
				(float)My_Out->a_b_e_L[0], (float)My_Out->a_b_e_L[1], (float)My_Out->a_b_e_L[2],
				&c_delf, &c_delm[0], &c_delm[1], &c_delm[2],
        Throttle_Stick_Mapped,Roll_Stick_Mapped,Pitch_Stick_Mapped,Yaw_Stick_Mapped,Manual,!Arm_Switch_State);



        if (Auto_Manual_Payload_State == 2){
          #if PRINT_KILL_AUTO_PAYLOAD  
          Serial.println("PAYLOAD DROP");
          #endif
          motors.Servo_Open();
        }else{
          motors.Servo_Closed();
        }


      }else{
        #if PRINT_KILL_AUTO_PAYLOAD  
        Serial.println("AUTO");
        #endif
        c_delf = -1;
        c_delm[0] = 0;
        c_delm[1] = 0;
        c_delm[2] = 0;
      }


      char LaunchState;
      updateMixer( Arm_Switch_State, &LaunchState,
        c_delf, c_delm[0], c_delm[1], c_delm[2],
        pwm);

        
    }
    #if PRINT_DT
    Serial.println("Controller");
    Serial.println(millis()- currentMillis);
    #endif
    #endif


    #if HAVE_THERMAL
    currentMillis = millis();
    if (currentMillis - previousMillisThermal >= intervalThermal) {
      previousMillisThermal = currentMillis;
        thermal.update();
        Fire_Found = thermal.Find_Fire(My_Out->p_b_e_L[2], 55, 35, Fire_Position);
        float Global_Fire_X_Error = cos(sens.data_POZYX.euler_rad[2]) * Fire_Position[0] - sin(sens.data_POZYX.euler_rad[2]) * Fire_Position[1];
        float Global_Fire_Y_Error = sin(sens.data_POZYX.euler_rad[2]) * Fire_Position[0] + cos(sens.data_POZYX.euler_rad[2]) * Fire_Position[1];
        Open_Time = millis() - Opened_Time;

        
        if (Fire_Found){
          My_Out->Fire_Detected = 1;
          My_Out->Fire_Location[0] = Global_Fire_X_Error + My_Out->p_b_e_L[0];
          My_Out->Fire_Location[1] = Global_Fire_Y_Error + My_Out->p_b_e_L[1];
          // cntrl->posDes[0] = My_Out->Fire_Location[0];
          // cntrl->posDes[1] = My_Out->Fire_Location[1];
          // cntrl->posDes[2] = 3;


          // Serial.print("Fire Found at body frame Delta: ");
          // Serial.print(Fire_Position[0]);
          // Serial.print(" , ");
          // Serial.print(Fire_Position[1]);
          // // Serial.print(" , ");
          // // Serial.print(sens.data_POZYX.euler_rad[2]);
          // Serial.println();

          // Serial.print("Gloabal Fire Position: ");
          // Serial.print(Global_Fire_X_Error);
          // Serial.print(" , ");
          // Serial.print(Global_Fire_Y_Error);
          // // Serial.print(" , ");
          // // Serial.print(My_Out->p_b_e_L[2]);
          // Serial.println();

          float Total_Global_Fire_Error = sqrt((Global_Fire_X_Error * Global_Fire_X_Error) + (Global_Fire_Y_Error * Global_Fire_Y_Error));
          float Acceptable_Fire_Error = .2;
          if (Total_Global_Fire_Error < Acceptable_Fire_Error || (Open_Time < 5000 && Opened == true)){
            //Serial.println("DROPPED");
            My_Out->Payload_Dropped = 1;
            motors.Servo_Open();
            if (Open_Time>5000){
              Opened_Time = millis();
            }
            
            Opened = true;
          }else{
            //Serial.println("CLOSED");
            motors.Servo_Closed();
            My_Out->Payload_Dropped = 0;
          }
        }else{
          My_Out->Fire_Detected = 0;
          //Serial.println("No Fire Found");
          if (Open_Time>3000){
            My_Out->Payload_Dropped = 0;
            //Serial.println("CLOSED");
            motors.Servo_Closed();
          }
          
          
        }
        

        


        #if PRINT_DT
        Serial.println("Thermal");
        Serial.println(millis()- currentMillis);
        #endif


    }
    #endif

    #if HAVE_DATALINK
    currentMillis = millis();
    if (currentMillis - previousData_Link_Send >= intervalData_Link_Send) {
      previousData_Link_Send = currentMillis;
      datalink.send_update(sens, c_delf, c_delm[0], c_delm[1], c_delm[2],rc.rc_in.THR,rc.rc_in.ROLL,rc.rc_in.PITCH,rc.rc_in.YAW,rc.rc_in.AUX2,rc.rc_in.AUX,pwm[0],pwm[1],pwm[2],pwm[3]);
    }

    #if PRINT_DT
    Serial.println("Data Link Send");
    Serial.println(millis()- currentMillis);
    #endif

    #endif


    #if HAVE_MOTORS
    currentMillis = millis();
    if (currentMillis - previousMillisMotors >= intervalMotors) {
      previousMillisMotors = currentMillis;
      motors.update(pwm);
    }
    #if PRINT_DT
    Serial.println("Motors");
    Serial.println(millis()- currentMillis);
    #endif
    #endif

    currentMillis = millis();
    if (currentMillis - previousMillisPrint >= intervalPrint) {
      previousMillisPrint = currentMillis;

      // Serial.print("KP: [");
      // Serial.print(cntrl->KP[0], 4); Serial.print(", ");
      // Serial.print(cntrl->KP[1], 4); Serial.print(", ");
      // Serial.print(cntrl->KP[2], 4); Serial.println("]");

      // Serial.print("KI: [");
      // Serial.print(cntrl->KI[0], 4); Serial.print(", ");
      // Serial.print(cntrl->KI[1], 4); Serial.print(", ");
      // Serial.print(cntrl->KI[2], 4); Serial.println("]");

      // Serial.print("KD: [");
      // Serial.print(cntrl->KD[0], 4); Serial.print(", ");
      // Serial.print(cntrl->KD[1], 4); Serial.print(", ");
      // Serial.print(cntrl->KD[2], 4); Serial.println("]");


      // Serial.println(rc.rc_in.Good_Reciever);
      // Serial.println(rc.rc_in.Good_Kill_Wire);
      //Serial.println(rc.rc_in.AUX);
      //Serial.println(rc.rc_in.Same_Count);
      //rc.print();
      //sens.print();
      // Serial.print("pwm: [");
      // Serial.print(pwm[0]);
      // Serial.print(", ");
      // Serial.print(pwm[1]);
      // Serial.print(", ");
      // Serial.print(pwm[2]);
      // Serial.print(", ");
      // Serial.print(pwm[3]);
      // Serial.println("]\n");

      // Serial.print("wx: ");
      // Serial.print(sens.data_POZYX.gyr_rad[0]);
      // Serial.print("wy: ");
      // Serial.print(sens.data_POZYX.gyr_rad[1]);
      // Serial.print("wz: ");
      // Serial.println(sens.data_POZYX.gyr_rad[2]);
      // Serial.print("UPDATE COUNTER:");
      // Serial.print(sens.data_POZYX.POZYX_Update_Counter);

      // Serial.print("c_del: [");
      // Serial.print(c_delf);
      // Serial.print(", ");
      // Serial.print(c_delm[0]);
      // Serial.print(", ");
      // Serial.print(c_delm[1]);
      // Serial.print(", ");
      // Serial.print(c_delm[2]);
      // Serial.println("]");

      // Serial.print("Stick_Values: [");
      // Serial.print(Throttle_Stick);
      // Serial.print(", ");
      // Serial.print(Roll_Stick);
      // Serial.print(", ");
      // Serial.print(Pitch_Stick);
      // Serial.print(", ");
      // Serial.print(Yaw_Stick);
      // Serial.println("]");

      // Serial.print("Stick_Values_MAPPED: [");
      // Serial.print(Throttle_Stick_Mapped);
      // Serial.print(", ");
      // Serial.print(Roll_Stick_Mapped);
      // Serial.print(", ");
      // Serial.print(Pitch_Stick_Mapped);
      // Serial.print(", ");
      // Serial.print(Yaw_Stick_Mapped);
      // Serial.println("]");

    }
 }

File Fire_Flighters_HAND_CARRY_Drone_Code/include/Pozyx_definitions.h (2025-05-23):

/*
  Pozyx_definitions.h - Library for Arduino Pozyx shield.
  Copyright (c) Pozyx Laboratories.  All right reserved.

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
  You should have received a copy of the GNU Lesser General Public
  License along with this library; if not, write to the Free Software
  Foundation, Inc., 51 Franklin St, Fifth Floor, Boston, MA  02110-1301  USA
*/

#ifndef POZYX_DEFINITIONS_h
#define POZYX_DEFINITIONS_h

#define _POZYX_LIB_VERSION          1
#define _POZYX_FEET_PER_METER       3.2808399
#define _POZYX_INCH_PER_METER       39.3700787

#define _POZYX_FORMAT_METER
#define _POZYX_FORMAT_FOOT
#define _POZYX_FORMAT_INCH

/* Maximum number of anchors to be stored in the interal anchor list on the pozyx device */
#define MAX_ANCHORS_IN_LIST      20

#define POZYX_I2C_ADDRESS        0x4B

/* Begin auto generated defines */
/* POZYX REGISTERS firmware version v1.0 */

/* Status registers */

#define POZYX_WHO_AM_I          0x0  /* Returns the constant value 0x43. */
#define POZYX_FIRMWARE_VER      0x1  /* Returns the POZYX firmware version. */
#define POZYX_HARDWARE_VER      0x2  /* Returns the POZYX hardware version. */
#define POZYX_ST_RESULT         0x3  /* Returns the self-test result */
#define POZYX_ERRORCODE         0x4  /* Describes a possibly system error. */
#define POZYX_INT_STATUS        0x5  /* Indicates the source of the interrupt. */
#define POZYX_CALIB_STATUS      0x6  /* Returns the calibration status. */

/* Configuration registers */

#define POZYX_INT_MASK          0x10   /* Indicates which interrupts are enabled. */
#define POZYX_INT_CONFIG        0x11   /* Configure the interrupt pin */
#define POZYX_POS_FILTER        0x14   /* Pozyx filter configuration register */
#define POZYX_CONFIG_LEDS       0x15   /* Configure the LEDs */
#define POZYX_POS_ALG           0x16   /* Algorithm used for positioning */
#define POZYX_POS_NUM_ANCHORS   0x17   /* Configure the number of anchors and selection procedure */
#define POZYX_POS_INTERVAL      0x18   /* Defines the update interval in ms in continuous positioning. */
#define POZYX_NETWORK_ID        0x1A   /* The network id.  */
#define POZYX_UWB_CHANNEL       0x1C   /* UWB channel number. */
#define POZYX_UWB_RATES         0x1D   /* Configure the UWB datarate and pulse repetition frequency (PRF) */
#define POZYX_UWB_PLEN          0x1E   /* Configure the UWB preamble length.  */
#define POZYX_UWB_GAIN          0x1F   /* Configure the power gain for the UWB transmitter */
#define POZYX_UWB_XTALTRIM      0x20   /* Trimming value for the uwb crystal. */
#define POZYX_RANGE_PROTOCOL    0x21    /* The ranging protocol */
#define POZYX_OPERATION_MODE    0x22   /* Configure the mode of operation of the pozyx device */
#define POZYX_SENSORS_MODE      0x23   /* Configure the mode of operation of the sensors */
#define POZYX_CONFIG_GPIO1      0x27   /* Configure GPIO pin 1. */
#define POZYX_CONFIG_GPIO2      0x28   /* Configure GPIO pin 2. */
#define POZYX_CONFIG_GPIO3      0x29   /* Configure GPIO pin 3. */
#define POZYX_CONFIG_GPIO4      0x2A   /* Configure GPIO pin 4. */

/* Positioning data */

#define POZYX_POS_X             0x30   /* x-coordinate of the device in mm. */
#define POZYX_POS_Y             0x34   /* y-coordinate of the device in mm. */
#define POZYX_POS_Z             0x38   /* z-coordinate of the device in mm. */
#define POZYX_POS_ERR_X         0x3C   /* estimated error covariance of x */
#define POZYX_POS_ERR_Y         0x3E   /* estimated error covariance of y */
#define POZYX_POS_ERR_Z         0x40   /* estimated error covariance of z */
#define POZYX_POS_ERR_XY        0x42   /* estimated covariance of xy */
#define POZYX_POS_ERR_XZ        0x44   /* estimated covariance of xz */
#define POZYX_POS_ERR_YZ        0x46   /* estimated covariance of yz */

#define POZYX_MAX_LIN_ACC       0x4E   /* maximum linear acceleration since */

/* Sensor data */
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

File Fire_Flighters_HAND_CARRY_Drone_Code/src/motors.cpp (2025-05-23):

/*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
 * Pennsylvania State University Unmanned Aerial System Research Laboratory (PURL)
 * Department of Aerospace Engineering
 * 229 Hammond
 * The Pennsylvania State University
 * University Park, PA 16802
 * http://purl.psu.edu
 *
 * Contact Information:
 * Dr. Thanakorn Khamvilai (thanakorn.khamvilai@ttu.edu)
 * Dr. Vitor T. Valente (vitor.valente@psu.edu)
 *
 * EndCopyright
 ***/

#include "../include/motors.h"

Motors::Motors()
{

}

Motors::~Motors()
{

}

void Motors::init()
{
  for(uint8_t i=0; i<NUM_MOTORS; i++)
    motor[i].begin(20000ul, TIMER_SOURCE_DIV_1); // 20000 us is 50 Hz

  this->stop();

  // wait to make sure everything is set
  delay(100); // it's okay to use delay in setup()

  Servo.begin(20000ul, TIMER_SOURCE_DIV_1);
}

void Motors::calibrate()
{
  // ESC calibration: send max and min PWM to the ESC
  // Calibration must be done only once when you have a new ESC

  for(uint8_t i=0; i<NUM_MOTORS; i++) motor[i].pulseWidth_us(MAX_PWM_OUT);
  delay(5000);
  for(uint8_t i=0; i<NUM_MOTORS; i++) motor[i].pulseWidth_us(MIN_PWM_OUT);
  delay(5000);
}

void Motors::Servo_Closed(){
  Servo.pulseWidth_us(SERVO_CLOSED);
}

void Motors::Servo_Open(){
  Servo.pulseWidth_us(SERVO_OPEN);
}

void Motors::stop()
{
  for(uint8_t i=0; i<NUM_MOTORS; i++) motor[i].pulseWidth_us(MIN_PWM_OUT);
}

void Motors::update(float pwm[NUM_MOTORS])
{
  for(uint8_t i=0; i<NUM_MOTORS; i++)
  {
    pwm[i] = constrain(pwm[i], MIN_PWM_OUT, MAX_PWM_OUT);
    motor[i].pulseWidth_us(pwm[i]);
  }
}

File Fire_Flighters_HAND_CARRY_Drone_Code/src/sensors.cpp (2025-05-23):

/*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
 * Pennsylvania State University Unmanned Aerial System Research Laboratory (PURL)
 * Department of Aerospace Engineering
 * 229 Hammond
 * The Pennsylvania State University
 * University Park, PA 16802
 * http://purl.psu.edu
 *
 * Contact Information:
 * Dr. Thanakorn Khamvilai (thanakorn.khamvilai@ttu.edu)
 * Dr. Vitor T. Valente (vitor.valente@psu.edu)
 *
 * EndCopyright
 ***/

#include "../include/sensors.h"
#include "../include/Pozyx.h"
#include "../include/Pozyx_definitions.h"
#include <Wire.h>

#define POZYX_GYR_SCALE 0.0625
#define POZYX_MAG_SCALE 0.0625
#define POZYX_EULER_SCALE 0.0625
#define POZYX_QUAT_SCALE 1.0/16384.0

float wrapAngleDeg(float angle) {
  angle = fmod(angle + 180.0, 360.0);
  if (angle < 0)
      angle += 360.0;
  return angle - 180.0;
}

Sensors::Sensors()
{
  for(uint8_t i = 0; i < 3; i++)
  {
    this->data_POZYX.gyr[i]   = 0;
    this->data_POZYX.acc[i]   = 0;
    this->data_POZYX.mag[i]   = 0;
    this->data_POZYX.euler[i] = 0;
    this->data_POZYX.quat[i]  = 0;

    this->bias.gyr[i]   = 0;
    this->bias.acc[i]   = 0;
    this->bias.mag[i]   = 0;
    this->bias.euler[i] = 0;
    this->bias.quat[i]  = 0;
  }
  this->data_POZYX.quat[0] = 1;
  this->calibration_flag = 0;
}

Sensors::~Sensors() {}

void Sensors::init()
{
  Serial.println("Init");
  if(Pozyx.begin(true, MODE_POLLING, POZYX_INT_MASK_IMU, 0x02) == POZYX_FAILURE)
  {
    Serial.println("ERROR: Unable to connect to POZYX shield");
    Serial.println("Reset required");
    delay(100);
    // abort();
  }
  if (NUM_CALIBRATION != 0){
    for(unsigned long i = 0; i < NUM_CALIBRATION; i++)
    {
      this->update();
      for(uint8_t j = 0; j < 3; j++)
      {
        this->bias.gyr[j]   += this->data_POZYX.gyr[j];
        this->bias.euler[j] += this->data_POZYX.euler[j];
      }
    }
    for(uint8_t i = 0; i < 3; i++)
    {
      this->bias.gyr[i]   /= NUM_CALIBRATION;
      this->bias.euler[i] /= NUM_CALIBRATION;

      this->data_POZYX.gyr[i]   = 0;
      this->data_POZYX.euler[i] = 0;
    }
}
  this->calibration_flag = 1;
}

void Sensors::update()
{
  sensor_raw_t sensor_raw;
  if (Pozyx.waitForFlag(POZYX_INT_STATUS_IMU, 1) == POZYX_SUCCESS){
    Pozyx.getRawSensorData(&sensor_raw);
  }else{
    uint8_t interrupt_status = 0;
    Pozyx.getInterruptStatus(&interrupt_status);
    return;
  }

  // Accelerometer Data needs to be added: CONVERTS from mg to g also has Z down X forward Y to complete set
  this->data_POZYX.acc[0] = sensor_raw.acceleration[1]/1000.0;
  this->data_POZYX.acc[1] = -sensor_raw.acceleration[0]/1000.0;
  this->data_POZYX.acc[2] = sensor_raw.acceleration[2]/1000.0;

  //Converts from g to ft/s^2
  this->data_POZYX.acc[0] = this->data_POZYX.acc[0]*32.1740;
  this->data_POZYX.acc[1] = this->data_POZYX.acc[1]*32.1740;
  this->data_POZYX.acc[2] = this->data_POZYX.acc[2]*32.1740;

  // YPR to RPY and NED
  this->data_POZYX.euler[0] = wrapAngleDeg(sensor_raw.euler_angles[1] * POZYX_EULER_SCALE); // convert to deg
  this->data_POZYX.euler[1] = wrapAngleDeg(sensor_raw.euler_angles[2] * POZYX_EULER_SCALE); // convert to deg
  this->data_POZYX.euler[2] = wrapAngleDeg(sensor_raw.euler_angles[0] * POZYX_EULER_SCALE); // convert to deg


  if(this->calibration_flag) // regular reading
  {
    float temp_gyr[3];
    temp_gyr[0] = sensor_raw.angular_vel[1] * POZYX_GYR_SCALE * -1.0; // convert to deg/s
    temp_gyr[1] = sensor_raw.angular_vel[0] * POZYX_GYR_SCALE * -1.0; // convert to deg/s
    temp_gyr[2] = sensor_raw.angular_vel[2] * POZYX_GYR_SCALE * -1.0; // convert to deg/s

    for(uint8_t i = 0; i < 3; i++)
    {
      this->data_POZYX.euler[i] -= this->bias.euler[i];
      temp_gyr[i]         -= this->bias.gyr[i];
      

    }

    // Serial.println(this->bias.euler[0]);
    // Serial.println(this->bias.euler[1]);
    // Serial.println(this->bias.euler[2]);
    // Serial.println("A");
    // Serial.println(this->bias.gyr[0]);
    // Serial.println(this->bias.gyr[1]);
    // Serial.println(this->bias.gyr[2]);

    // Serial.println("BB");

    for(uint8_t i = 0; i < 3; i++)
    {
      this->data_POZYX.gyr[i] = LOWPASS_WEIGHT*this->data_POZYX.gyr[i] + (1-LOWPASS_WEIGHT)*temp_gyr[i]; // low-pass filter
    }

  }
  else // calibration step
  {
    this->data_POZYX.gyr[0] = sensor_raw.angular_vel[1] * POZYX_GYR_SCALE * -1.0; // convert to deg/s
    this->data_POZYX.gyr[1] = sensor_raw.angular_vel[0] * POZYX_GYR_SCALE * -1.0; // convert to deg/s
    this->data_POZYX.gyr[2] = sensor_raw.angular_vel[2] * POZYX_GYR_SCALE * -1.0; // convert to deg/s
    
  }

  // THIS WILL CORRECT FOR THE WEIRD ASS ORIENTATION OF THE POZYX

  this->data_POZYX.gyr[0] = -this->data_POZYX.gyr[0];
  this->data_POZYX.euler[0] = -this->data_POZYX.euler[0];
  this->data_POZYX.gyr[2] = -this->data_POZYX.gyr[2];
  this->data_POZYX.euler[2] = -this->data_POZYX.euler[2];

  // std::swap(this->data_POZYX.acc[1], this->data_POZYX.acc[2]);


  // this->data_POZYX.acc[2] = -this->data_POZYX.acc[2];

  for(uint8_t i = 0; i < 3; i++)
  {
    this->data_POZYX.gyr_rad[i] = this->data_POZYX.gyr[i]*PI/180.0;
    this->data_POZYX.euler_rad[i] = this->data_POZYX.euler[i]*PI/180.0;
  }
  this->data_POZYX.POZYX_Update_Counter ++;
}

void Sensors::print()
 {
  
   Serial.print(this->data_POZYX.gyr[0]);// roll rate
   Serial.print(",");
   Serial.print(this->data_POZYX.gyr[1]);// pitch rate
   Serial.print(",");
   Serial.print(this->data_POZYX.gyr[2]);// yaw rate
  
   Serial.print("     ");
  
   Serial.print(this->data_POZYX.acc[0]); // x acc 
   Serial.print(",");
   Serial.print(this->data_POZYX.acc[1]); // y acc
   Serial.print(",");
   Serial.print(this->data_POZYX.acc[2]); // z acc
   Serial.print(",");
  
 
   Serial.print("     ");


   Serial.print(this->data_POZYX.euler[0]); //roll angle
   Serial.print(",");
   Serial.print(this->data_POZYX.euler[1]); //pitch angle
   Serial.print(",");
   Serial.print(this->data_POZYX.euler[2]); //yaw angle
   Serial.println();
 }

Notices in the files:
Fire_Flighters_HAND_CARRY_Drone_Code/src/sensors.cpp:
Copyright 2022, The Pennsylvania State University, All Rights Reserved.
